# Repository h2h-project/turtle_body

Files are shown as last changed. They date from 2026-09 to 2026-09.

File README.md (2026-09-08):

# turtle_body
The 3D design files that make up the components of the hope turtle's body.  

**Turtle Body** is the open-source mechanical design repository for the [Hope Turtle Project](https://hopeturtles.org): a wind-powered, largely organic marine vessel designed to carry food, building materials, love and hope toward coastal destinations. It is the physical counterpart to [TurtleOS](https://github.com/h2h-project/turtleOS), which handles sensing and autonomous navigation; the TurtleShell PCB, which connects and powers the electronics; and [HopeTurtles.org](https://github.com/h2h-project/hopeTurtles.org), which supports building, mission planning, tracking and discovery reporting. Together, these parts are intended to make Hope Turtles practical to reproduce, study and improve anywhere in the world.

This repository contains the parametric OpenSCAD models and fabrication files used to build the turtle body, including its bottle interfaces, control cap, rotating sail cage, magnetic angle-sensing shaft, bearing surfaces, sail battens and crossbars, chassis connections, rear fin and ballast components. The designs are being developed around ordinary bottles, locally available wooden boards and accessible 3D printing, with core measurements—such as bottle diameter, wood thickness, running clearance, hole size and component spacing—kept adjustable wherever possible. Source `.scad` files are retained as the editable designs from which printable STL models and other fabrication outputs can be generated.

The Turtle Body models are the geometry source behind the turtle generator on [HopeTurtles.org](https://hopeturtles.org/ecojoiners/generate). A builder enters the measurements of locally available bottles, boards and solar panels, and Python generators in the website repository's `generator/` directory produce cutting files for the wooden components. This repository's `lib/params.scad` is the authoritative dimension contract; the generators follow it, and `CLAUDE.md` section 19 records how changes made here are carried across so that each new iteration becomes easier for other builders to reproduce and adapt.

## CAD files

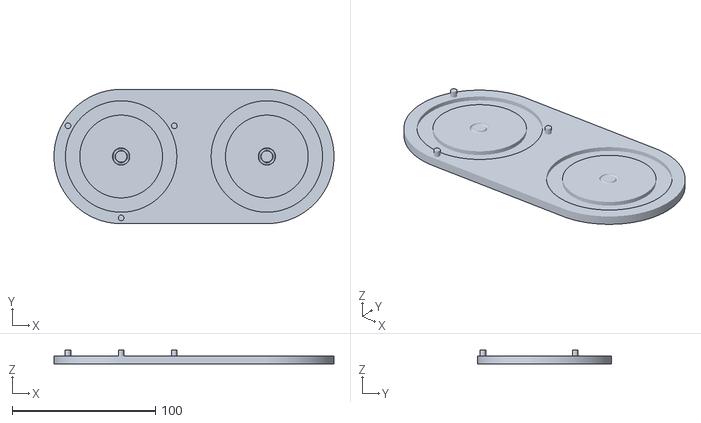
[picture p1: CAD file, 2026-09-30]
stls_v1/Silicone_Ring_Mold_bottom_v4.1.2.stl
195.5 x 93.8 x 9.60

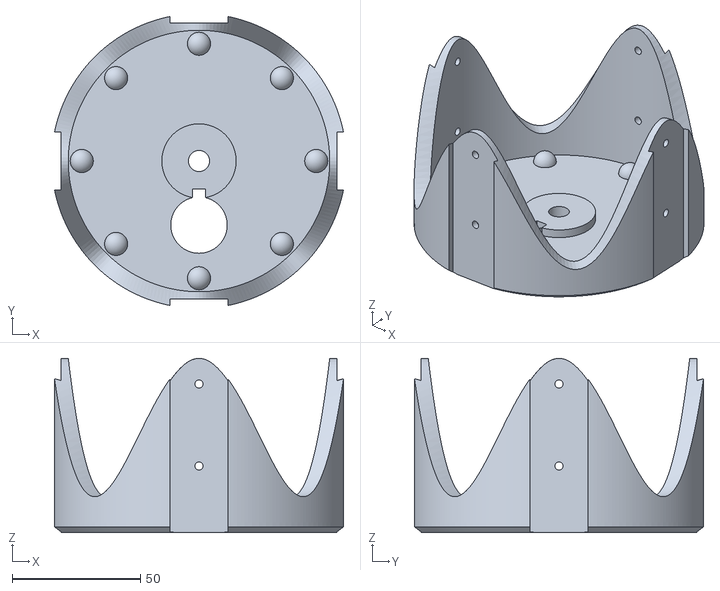
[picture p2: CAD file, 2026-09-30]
stls_v1/Bottle_Control_Cage_v4.1.2.stl
112.8 x 112.8 x 68.0

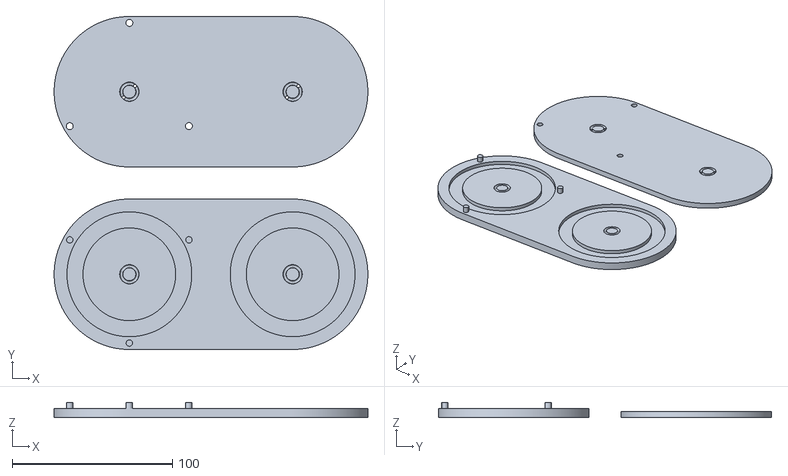
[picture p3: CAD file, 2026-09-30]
stls_v1/Silicone_Ring_Mold_v4.1.2.stl
195.5 x 207.5 x 9.60

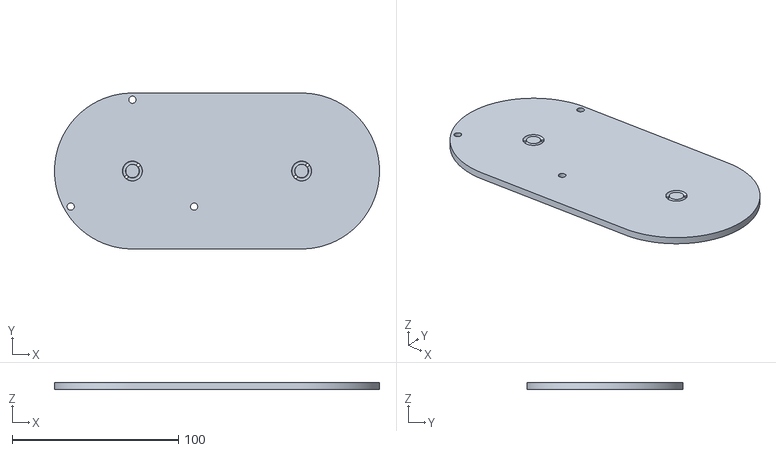
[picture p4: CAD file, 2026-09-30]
stls_v1/Silicone_Ring_Mold_top_v4.1.2.stl
195.5 x 93.8 x 4.00

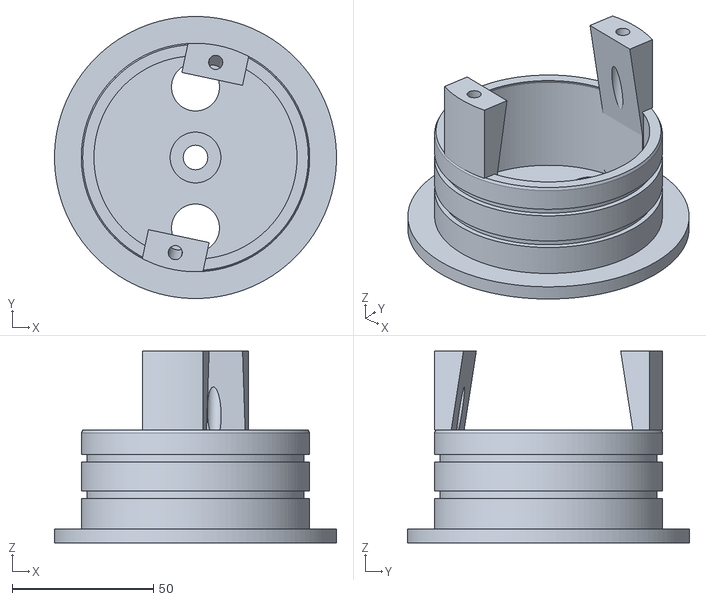
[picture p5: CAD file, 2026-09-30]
stls_v1/Bottle_Control_Cap_v4.1.2.stl
100.0 x 100.0 x 68.0

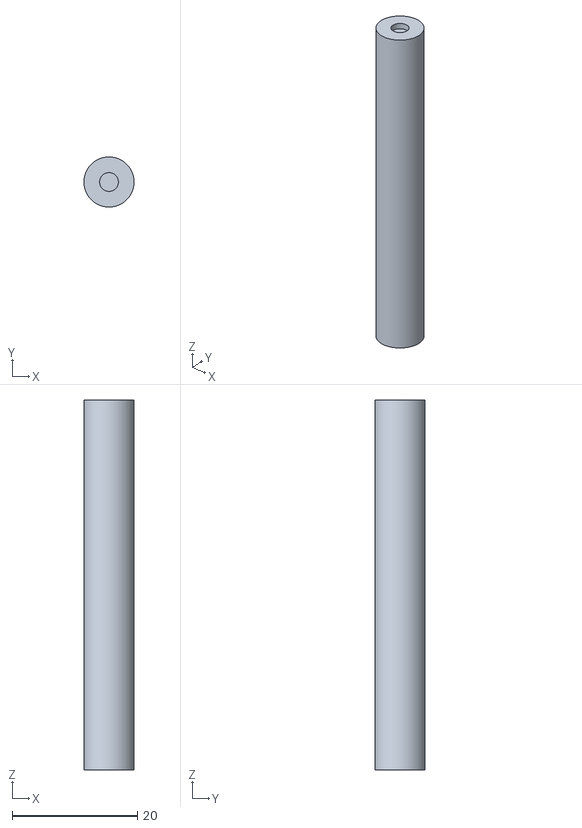
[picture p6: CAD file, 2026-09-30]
stls_v1/Bottle_Sail_Shaft_v4.1.2.stl
8.00 x 8.00 x 59.0

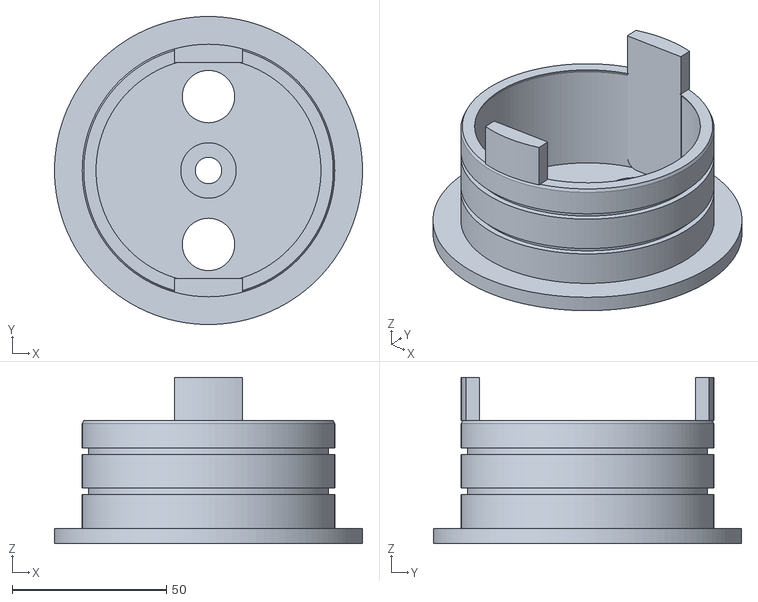
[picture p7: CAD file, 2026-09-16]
stls_v1/Bottle_Control_Cap_v1X.stl
100.0 x 100.0 x 54.0

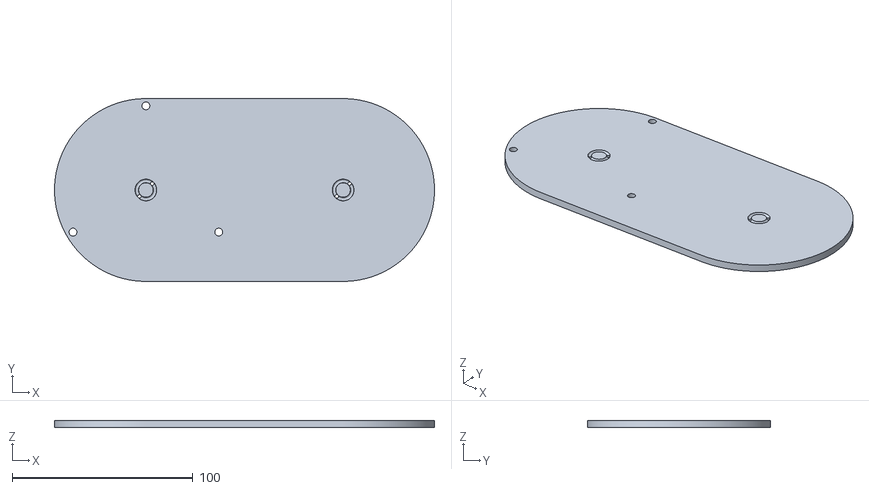
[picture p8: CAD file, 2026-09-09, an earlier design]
stls_v1/Silicone_Ring_Mold_top_v1.10.0.stl
210.0 x 101.0 x 4.00

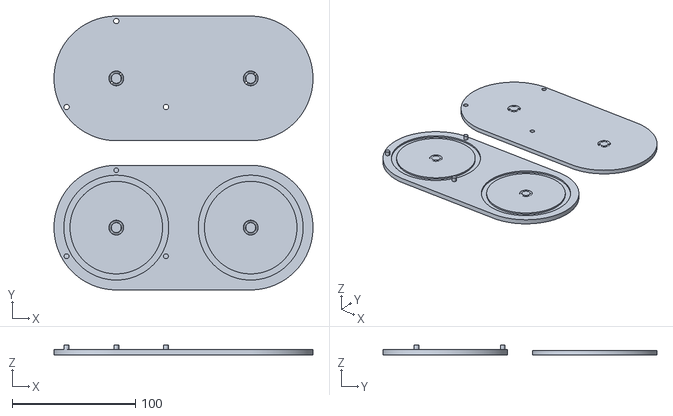
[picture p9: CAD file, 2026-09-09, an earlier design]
stls_v1/Silicone_Ring_Mold_v1.10.0.stl
210.0 x 222.0 x 8.50

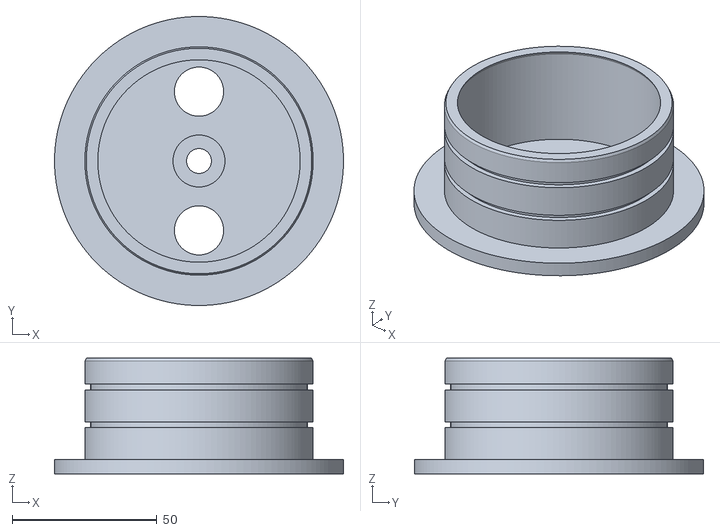
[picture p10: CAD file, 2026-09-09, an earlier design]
stls_v1/Bottle_Control_Cap_v1.10.0.stl
100.0 x 100.0 x 40.0

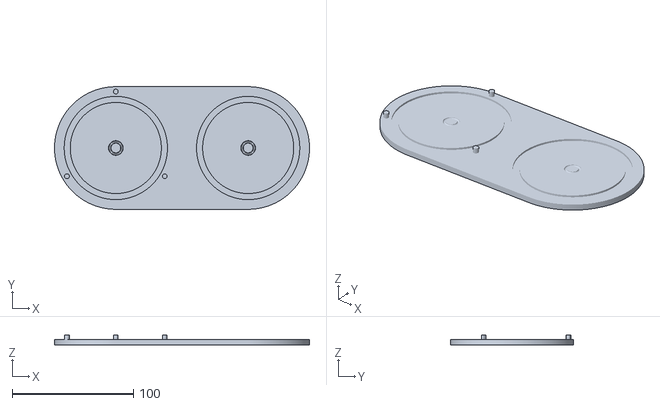
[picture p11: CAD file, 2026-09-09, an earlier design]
stls_v1/Silicone_Ring_Mold_bottom_v1.10.0.stl
210.0 x 101.0 x 8.50

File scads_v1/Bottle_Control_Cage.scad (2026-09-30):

// ==========================================================================
//  GENERATED FILE -- DO NOT EDIT.
//  Produced by build/build.py from components/Bottle_Control_Cage.scad
//  Turtle Body version 4.1.2
//  Edit lib/ and src/ instead, then run: python3 build/build.py
// ==========================================================================
/*
 Hope Turtle — scalloped, reinforced PLA cage. Units: mm.
 Matched to the control cap: 100 mm cap disk, 102 mm cavity, 1 mm radial
 clearance. One continuous sinusoidal wall -> four rounded crests roof-down;
 each batten groove + its two M3 holes centred on a crest. No separate tabs.

 FABRICATION: this part is 3D-PRINTED ROOF-FACE-DOWN — the flat top surface
 goes on the printer bed (part="print" flips it). Any change to the roof top
 must stay self-supporting in that pose: bevels flare OUTWARD from the bed
 (<= 45 deg), no undercut, no downward-facing pocket/lip/overhang. Flag any
 change that would need support material instead of making it silently.
 Horizontal M3 bores bridge in the slicer. The recessed clip pocket around
 the axle is OFF by default (top_pocket) while prototyping without a clip.
 TB-08: the central bore is a plain round hole for the uniform round sail
 shaft (see Bottle_Sail_Shaft.scad); a single radial M3 set screw through
 the hub wall locks the shaft to the cage; it points into the roof button
 opening so a hex key reaches it from above. Prototype: not load-tested.
 Test fit, torsion, bending, layer adhesion, set-screw thread engagement.

 SOURCE FILE — geometry lives in lib/control_cage.scad + lib/params.scad.
 The committed self-contained file is generated by build/build.py.
*/

/* [View] */
part = "print"; // [print,upright]
curve_segments = 120; // [48:12:240]
wave_segments  = 240;  // [120:24:480]

/* [Cage body] */
cage_wall   = 6.5;
cage_roof   = 4;
skirt_height = 44;      // roof underside -> ORIGINAL skirt rim
notch_width = 22.5;
notch_depth = 3.7;
m3_hole_diameter = 3.2;
roof_ring_height = 10;  // minimum skirt depth between mounts
mount_extension  = 20;  // crest past the original rim
lower_hole_from_tip = 10;
roof_bevel = 3;         // 45-deg outward chamfer on the roof-top edge (0 = sharp); prints face-down

/* [Bearings and button] */
bump_d = 9;
button_diameter = 22;  // opens onto the hub face -> set-screw access
button_r = 25;         // matches the cap's button holes (p_button_radius())
button_angle = 90; // [0:0.5:359.5]

/* [Shaft hub, lock screw and clip pocket] */
shaft_hole_diameter = 8.2;  // TB-08: round bore, shaft dia + running clearance (was a hex bore)
cage_hub_d = 29;
setscrew_pilot_diameter = 2.5;  // self-tapping M3 grub-screw pilot, untested thread engagement
setscrew_recess_width = 5;      // key-access recess around the screw (tangential)
setscrew_recess_depth = 3;      //   "  radial, inward from the opening edge (0 = none)
top_pocket = false;      // recessed clip pocket around the axle (off while prototyping)
clip_pocket_depth = 4;   // used only when top_pocket = true
pocket_d = 26;           //   "    "    "     "      "

// [bundle] begin use <../../lib/control_cage.scad>
// ==========================================================================
//  Turtle Body -- rotating control cage  (lib module)
// --------------------------------------------------------------------------
//  An inverted open-bottom cup. One continuous sinusoidal annular wall
//  forms four rounded crests; each batten groove and its two M3 holes are
//  centred on a crest. Eight solid hemispherical bearing bumps ride on the
//  cap's flat face. No bottom plate, no separate tabs. See CLAUDE.md s6.
//
//  Native "installed" reference: bearing tips touch cap Z = 0.
//    roof underside  Z = bump_d/2         (= 4.5 default)
//    roof top        Z = bump_d/2 + roof  (= 10.5)
//    longest tip     Z = -(skirt + extension) + bump_d/2   (= -59.5)
//
//  FABRICATION -- READ BEFORE CHANGING THE ROOF: this part is 3D-PRINTED
//  ROOF-FACE-DOWN. The flat top surface goes on the printer bed (the
//  wrapper's part="print" pose flips it; see CLAUDE.md s6 / s16). Every
//  roof-top feature must be self-supporting in that orientation:
//    * a bevel/chamfer on the roof-top edge must flare OUTWARD as it rises
//      from the bed (<= 45 deg from vertical) -- p_cage_roof_bevel() is a
//      true 45-deg outward chamfer and is printable as-is;
//    * do NOT add a downward-facing pocket, lip or overhang to the roof top,
//      and do NOT make the bevel an undercut (radius growing then shrinking).
//  A change that would need support material in the roof-down pose must be
//  flagged to the user, not silently made. The horizontal M3 bores (batten
//  mounts + the TB-08 shaft set screw) bridge in the slicer; keep them
//  inspectable. The recessed clip pocket around the axle is behind
//  `top_pocket` (OFF by default -- no shaft clip while prototyping).
//
//  TB-08: the central bore is now a plain round hole (shaft_hole_d, shared
//  with the sail bar's own hole) that the uniform round shaft passes
//  through with a light running clearance -- not a shaped (hex)
//  interference fit. A single radial M3 set screw through the hub wall
//  (setscrew_pilot_d/setscrew_angle) presses on the shaft to lock it to the
//  rotating cage. The pilot is a self-tapping hole into the printed PLA hub,
//  not a clearance hole for a separate nut -- untested thread engagement.
//
//  Definitions only. Geometry is emitted by control_cage(); the wrapper /
//  full assembly applies the print-pose or installed transform.
// ==========================================================================

// [bundle] begin use <params.scad>
// ==========================================================================
//  Turtle Body -- shared dimension contract
// --------------------------------------------------------------------------
//  The single source of truth for every dimension that more than one
//  subsystem depends on. Values are exposed as zero-argument functions so
//  this file can be pulled in with `use <params.scad>` (which ignores
//  top-level variable assignments) without polluting any namespace.
//
//  lib/ modules take these as DEFAULT argument values:
//      module control_cap(roof_t = p_cap_roof_t(), ...) { ... }
//  so a src/ wrapper can still override one value from its customizer block
//  while every other subsystem keeps the shared number.
//
//  Rules:
//   * one function per concept, canonical name (see CLAUDE.md cross-file table)
//   * derived values are functions of other p_*() functions, never re-typed
//   * mm throughout; names say _d (diameter), _r (radius), _t (thickness),
//     _len / _h (axial), _af (hex across-flats)
//   * do NOT add a bare `x = ...;` here -- bundle.py / lint.py will reject it
// ==========================================================================

// ---- tolerances and render quality --------------------------------------
function p_eps()          = 0.02;   // Boolean overlap / cut-through fudge
function p_fit_clearance() = 0.2;   // wood joint: TOTAL extra slot width, centred on the board
function p_fn_plastic()   = 120;    // printed PLA parts (cap, cage, axle, mold)
function p_fn_wood()      = 96;     // cut wooden parts
function p_fn_curve()     = 180;    // fine profile curves (bottle, sails)

// ---- bottle (the foundation reference) ---------------------------------
function p_bottle_d()        = 84;    // outside diameter (was 86, and 82 before that; other bottle dims held)
function p_bottle_h()        = 305;   // total height incl. ordinary screw cap
function p_bottle_wall_t()   = 0.5;   // modelling assumption, not a measurement
function p_bottle_cap_d()    = 31;    // ordinary screw cap (NOT the control-cap disk)
function p_bottle_cap_h()    = 17;    // ordinary screw cap height (rear-fin / ballast formulas)
function p_collar_d()        = 34;    // bottle collar, independent of cap diameter
function p_top_dome_h()      = 62;
function p_bottom_dome_h()   = 25;
function p_dome_power()      = 2.5;   // superellipse exponent
function p_bottle_neck_h()   = 5;
function p_bottle_collar_h() = 1;
function p_bottle_neck_d()   = p_bottle_cap_d() - 3;   // 28: neck is 3 mm under the cap
function p_bottle_base_ratio() = 0.88; // slightly narrower footprint at the base
function p_bottle_profile_steps() = 16;
// cut bottle (control head): the lower dome is removed and a short socket is
// bored so the control-cap insert slides in. Cut plane sits 5 mm above the
// bottom dome height.
function p_bottle_cut_extra()  = 5;
function p_bottle_cut_height() = p_bottom_dome_h() + p_bottle_cut_extra();   // 30
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

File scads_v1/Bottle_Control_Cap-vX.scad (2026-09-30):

/*
 Hope Turtle — control cap, EXPERIMENTAL side-tab variant "vX". Units: mm.
 License: CERN-OHL-S-2.0.

 HAND-BUILT ONE-OFF VARIANT — NOT a generated bundle, NOT produced by
 build/build.py, NOT wired into build/manifest.json. Forked from the
 production src/components/Bottle_Control_Cap.scad / lib/control_cap.scad
 (turtle_body v4.0.0). Everything outside the side tabs (disk, insert,
 O-ring gland, band channels, button holes, asserts) is copied verbatim from
 lib/control_cap.scad; only the side-tab placement/taper/wire-channel logic
 below is a hand-modified fork (see the precedent: v1.0
 SCADs/Bottle_Control_Cap_v1XX.scad).

 SELF-CONTAINED (2026-09-23): lib/params.scad and lib/util.scad are pasted
 inline below (between the "[bundle] begin/end" markers), snapshotted at
 turtle_body v4.0.0. No other files are needed to open or render this file.
 Consequence: it no longer tracks lib/params.scad — a later lib change must
 be re-bundled by hand (python3 build/bundle.py on a copy with the two
 `use <../lib/...>` lines restored).

 Revision history (all 2026-09-22):

 Rev 1: no rotation off the button axis; each tab slides sideways by
 tab_side_offset (mirrored +6/-6); taper removed (straight inner face).

 Rev 2/3: chased a "still looks rotated" report by dropping the curved
 (wall-hugging) outer face for a flat one, and fixed the offset from
 mirrored to both-same-direction.

 Rev 4 (this one) — reverts the flat outer face. Confirmed from the actual
 renders: a flat/unclipped outer face is what looked like "ugly rectangles"
 that don't match the cap's round wall. The outer face is curved again —
 intersected against the TRUE cavity-wall / insert-wall cylinders (centred
 on the real cap axis, unmoved), same as lib/control_cap.scad's production
 cap_side_tabs() — so it genuinely follows the wall's own curvature. This is
 safe (not the rev-1 "diagonal" bug) because that block and that cylinder
 are BOTH invariant along Z within each segment: intersecting a fixed 2-D
 footprint with a fixed-radius cylinder, repeated unchanged at every height,
 produces a perfectly vertical curved wall, not a sloped/diagonal one. What
 actually varies is the plan (top-down) shape: since the tab is offset from
 the wall's own centre, its curved outer face naturally sits a little closer
 to the true wall on the side nearer the offset direction and a little
 farther on the other side — that asymmetry IS "matching the curve of a
 wall you're not centred on," not a defect. The two things rev 2/3 also
 fixed are kept:
   - x_off (tab_side_offset) is the SAME for both tabs — a uniform slide,
     not mirrored.
   - Inner face stays a straight vertical line (no taper) top to bottom.
   - Wire channel: 4 mm dia, blind, exits at the radial centre of the cap's
     own insert-wall thickness (not into the hollow cavity), cut in the
     outer/global difference() so it can reach past the tab's own material.
 As in production, the rib (inside the cavity height, Z <= lip_z) clips to
 the true cavity-wall radius (r_outer_true); the lip extension (free-
 standing above the cap's own body, Z > lip_z) clips to the true insert
 outer-wall radius (r_wall_true) — the same real step production always
 had, just now off-axis instead of on it.

 Rev 5 (this one) — two more changes:
  (a) The tab's INNER face is now positioned by a new adjustable variable,
      tab_inner_wall_distance (2 cm / 20 mm default), measured INWARD from
      the true outer wall radius (r_wall_true -- the cap's actual outer
      diameter along the button axis), not from the cavity wall the way
      tab_depth used to work. r_inner = r_wall_true - tab_inner_wall_distance.
      This reaches much deeper into the cap than the old 2 mm tab_depth did
      (r_inner drops from ~34.5 mm to ~20.5 mm at the current 81 mm insert
      diameter) -- comfortably still clear of the centre boss, asserted.
  (b) Wire channel direction reversed back to angling INWARD and breaking
      into the HOLLOW CAVITY, not blind in the solid wall the way rev 2-4
      had it. entry_r stays centred in the tip's own material; exit_r is
      now max(0, r_inner - wire_hole_d) -- a full hole-diameter past the
      (now much deeper) inner face, same formula production always used.
      The open end remains at the tip (outside, where a wire is fed in);
      what changed is where the OTHER end opens -- now on the inside of the
      cap (the cavity), not dead-ending in the wall's own material.

 Rev 6 (this one) — new silicone-seal strategy for the two insert-wrap seal
 grooves (cap_plug_outer()'s one_groove(), separate from the small axle
 O-ring gland). Production/rev 1-5 cut a RECTANGULAR slot (flat floor,
 square corners: 2.7 mm wide x 2 mm deep) meant for a flat cast ring
 (lib/silicone_ring_mold.scad's flat-ring mold). This instead cuts a
 SEMICIRCULAR channel -- open flush with the insert's true outer surface,
 curving inward to a rounded floor -- sized to seat a round-section O-ring:
   band_channel_depth (kept at the same 2 mm) IS the semicircle's radius,
   so the groove's open width is always 2 x band_channel_depth (4 mm), and
   that's also the O-ring's own cross-section diameter -- half its
   thickness recesses into the groove, half stands proud of the surface for
   compression sealing, same convention as the existing axle O-ring gland.
 band_channel_w is gone as an independent input (width is now derived, not
 free); the two groove positions (band1/2_center_z_local) are unchanged.
 NOT yet matched on the casting side: lib/silicone_ring_mold.scad still
 only casts FLAT rectangular rings -- it would need a round-torus mold (like
 the small axle O-ring's own two-part mold there) sized to this new 4 mm
 cross-section before this groove shape could actually be filled with a
 matching cast part. Flagged, not implemented here (out of scope of "the
 groove on the cap" as asked).

 Rev 7 (this one) — two changes:
  (a) tab_inner_wall_distance default 20 -> 12 mm (r_inner now sits ~7.5 mm
      further out, closer to the true outer wall, still clear of the centre
      boss per the existing assert).
  (b) New faint reference etch line: a shallow (0.2 mm deep, 0.6 mm wide)
      groove recessed into the cavity ceiling (roof underside, the inner
      face you see looking up into the hollow insert), spanning the full
      cavity diameter along button_axis -- i.e. it passes through the centre
      bore and both button centres. Alignment mark only, no structural role.
      New inputs: etch_line_enable / etch_line_width / etch_line_depth.

 Rev 8 (this one) — four changes:
  (a) tab_wire_hole_diameter 4 -> 7 mm.
  (b) centre_boss_diameter: 12 mm was requested but fails the existing
      O-ring-gland-clearance assert (needs boss_d > gland OD + 1 mm = 12.5);
      set to 13 mm, the smallest value that still clears it.
  (c) New button_axis_offset (6 mm): both button holes now slide off the
      etched axle line, same direction as tab_side_offset (mirrors the tab
      slide, not mirrored left/right). Clearance asserts on button_radius
      now use the true centre distance (hypot of radius and offset), not
      just the nominal radius.
  (d) Button spacing: 18 mm centre-to-centre was requested but is not
      reachable at the existing 17 mm button diameter (the two holes would
      nearly touch each other and swallow the centre boss/bore). Per
      instruction, kept button_upper_d at 17 mm and used the real minimum
      spacing instead: hole_spacing_cc (radius) 25 -> 15 mm, giving 30 mm
      true centre-to-centre spacing (smallest that clears the 13 mm boss
      with ~1 mm margin, accounting for the offset in (c)).

 Rev 9 (this one) — two changes:
  (a) Tab wire channel's cavity-side opening moved: it now breaks through
      exactly at the cap's own inside corner -- where the flat roof
      (z = roof_t) meets the cavity wall (r = r_outer_true) -- instead of
      partway down the rib at a z = lip_z - wire_hole_exit_from_lip offset
      (that parameter is gone). The open end at the tip is unchanged.
  (b) New rectangular PCB-spacer notch in each tab's leg (the lip-extension
      portion beyond lip_z that sticks out past the cap body): starts
      tab_notch_from_lip (5 mm) past the lip, cuts tab_notch_depth (5 mm)
      radially in from the tab's inner face, and runs tab_notch_height
      (8 mm) further up the leg toward the tip. Full tab width. New module
      cap_tab_notches_vX(); new inputs tab_notch_enable /
      tab_notch_from_lip / tab_notch_depth / tab_notch_height.
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

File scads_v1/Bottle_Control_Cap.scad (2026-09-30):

// ==========================================================================
//  GENERATED FILE -- DO NOT EDIT.
//  Produced by build/build.py from components/Bottle_Control_Cap.scad
//  Turtle Body version 4.1.2
//  Edit lib/ and src/ instead, then run: python3 build/build.py
// ==========================================================================
/*
 Hope Turtle — control cap for the current full-turtle sine cage. Units: mm.
 License: CERN-OHL-S-2.0.
 Cap disk 100 mm; matching cage cavity 102 mm (1 mm radial clearance).
 Print bearing face down at Z=0, open insert + boss facing up.
 5 mm roof + 2 mm internal boss (TB-03).
 The axle bore carries an O-ring gland (rotary seal on the spinning axle
 round section) -- waterproofs the bore. O-ring is cast in Silicone_Ring_Mold.
 Side tabs (two internal cavity ribs + lip extension, on by default) are a
 fit/registration experiment -- not validated. See lib/control_cap.scad.
 Each tab carries a 5 mm wire-routing channel down to the cavity, for
 button wiring.

 SOURCE FILE — geometry lives in lib/control_cap.scad + lib/params.scad.
 The committed self-contained file is generated by build/build.py.
*/

/* [Cap body] */
top_disk_thickness  = 5;   // roof / disk thickness
centre_boss_depth   = 1.5; // extra projection of the boss into the hollow cap (was 2; lowered 0.5 mm)
centre_boss_diameter = 18;
cup_wall_thickness  = 4;
insert_total_h      = 35;
entry_chamfer_h     = 1;
entry_chamfer_delta = 1;

/* [Axle and buttons] */
shaft_hole_d   = 8.7;  // 0.35 mm radial clearance to the Ø8 axle (was 8.6 / 0.3 mm)
button_upper_d = 17;
button_axis    = "y"; // [x,y]
hole_spacing_cc = 25;  // radial position of the two button centres (was 24; moved 1 mm out,
                        // shared with the cage's matching bore via p_button_radius())

/* [Axle O-ring gland] */
oring_gland_enable = true;
oring_gland_od = 11.5;      // groove bottom diameter in the bore
oring_gland_width = 2.6;    // groove axial width
oring_gland_from_face = 3.5; // groove centre, below the cap outer face

/* [Silicone band channels] */
band_channels_enable = true;
band_count = 2;             // [0:1:2]
band1_center_z_local = 12;  // groove centre, from the insert shoulder
band2_center_z_local = 25;
band_channel_w = 2.7;      // groove axial height (matches the retuned mold ring)
band_channel_depth = 2;    // groove radial depth

/* [Side tabs] */
// Two internal ribs on the hollow insert cavity's inner wall, on the button
// axis, running the full cavity height then continuing past the top lip as
// a free post with a gradual inward taper. Not validated -- a
// fit/registration experiment; see lib/control_cap.scad.
side_tabs_enable = true;
tab_width  = 22;   // tangential width, measured at the cavity-wall radius
tab_depth  = 2;    // radial projection inward from the cavity wall
tab_top_overhang = 28;  // how far the tabs continue past the top lip
tab_corner_fillet = 4;  // rounds the two bottom edges where the tab meets the floor
tab_tip_taper_gain = 6; // total inward (radial) lean of the inner face by the free tip
tab_taper_start = 10;   // taper begins this far below the lip
tab_rotate = -12;        // extra rotation of the tab pair about Z, off the button
                         // axis (- = clockwise, viewed from above)

/* [Tab wire hole] */
// A 5 mm channel drilled down each tab from its exposed free tip, angled
// so it breaks through into the hollow cavity for routing button wires.
tab_wire_hole_enable = true;
tab_wire_hole_diameter = 5;
tab_wire_hole_exit_from_lip = 15;  // how far below the lip the channel opens into the cavity

/* [Render] */
fn = 120; // [48:8:240]

// [bundle] begin use <../../lib/control_cap.scad>
// ==========================================================================
//  Turtle Body -- control cap  (lib module)
// --------------------------------------------------------------------------
//  The large stationary disk. Its insert enters the cut bottle body; the
//  rotating cage sits above its flat outer face. NOT the bottle's Ø31 screw
//  cap. See CLAUDE.md s7 / s8.
//
//  TB-03: 5 mm roof + 2 mm internal boss (7 mm axle bearing length).
//  The boss is joined to the roof with a Boolean overlap and survives the
//  cavity subtraction; the central bore passes through both.
//
//  The bore carries an O-RING GLAND (`oring_gland`, on by default): an
//  annular groove in the bore wall that seats a round-section rotary-seal
//  O-ring against the spinning axle round section, waterproofing the bore.
//  The O-ring is cast in lib/silicone_ring_mold.scad; its ID is tied to the
//  axle shaft (p_axle_oring_id() = p_axle_round_d()).
//
//  Optional SIDE TABS (`side_tabs`, off by default in this module but ON in
//  the wrapper): two internal ribs on the hollow insert cavity's inner wall,
//  rooted at the cavity floor, that continue past the top lip as a free
//  full-wall-thickness post with a gradual inward taper. See cap_side_tabs()
//  below. Not validated -- a fit/registration experiment.
//
//  Optional TAB WIRE HOLE (`tab_wire_hole`, off by default, ON in the
//  wrapper alongside side_tabs): a round channel drilled down each side
//  tab from its exposed free tip to a point inside the cap body, breaking
//  through the tab's inner face into the hollow cavity -- for routing
//  button wires from outside, down through the tab, into the cap interior.
//
//  Definitions only. Geometry is emitted by control_cap().
// ==========================================================================
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

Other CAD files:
stls_v1/Bottle_Control_Cage_v1.10.0.stl
v1.0 SCADs/Bottle_Control_Cap_v1X.scad
Full_Turtle_v1.scad
_hole_probe5.scad
scads_v1/Bottle_Sail_Shaft.scad
scads_v1/Silicone_Ring_Mold-vX.scad
scads_v1/Silicone_Ring_Mold.scad
scads_v1/Turtle_Bottom_Ballast_Fin.scad
scads_v1/Turtle_Core_Ecojoiner.scad
scads_v1/Turtle_Rear_Fin.scad
scads_v1/Turtle_Sail_Apparatus.scad
src/Full_Turtle.scad
src/components/Bottle_Control_Cage.scad
src/components/Bottle_Control_Cap.scad
src/components/Bottle_Sail_Shaft.scad
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

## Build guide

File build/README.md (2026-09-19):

# Turtle Body build system

Local, no network, no CI service. Python 3 standard library + OpenSCAD only.

## Layout

| Path | Role |
| --- | --- |
| `lib/*.scad` | **Editable.** One parametric module per subsystem, plus `params.scad` (the shared dimension contract, exposed as `function p_*()`), plus `util.scad`. Definitions only — no top-level geometry, no top-level variable assignments. |
| `src/Full_Turtle.scad`, `src/components/*.scad` | **Editable.** Thin wrappers: customizer block + `use <../lib/...>` + a `part=` / `assembly_view` dispatch. No geometry of their own. |
| `Full_Turtle_v1.scad`, `scads_v1/*.scad` | **Generated. Do not edit.** Self-contained bundles produced from `src/` + `lib/`. Committed so they stay downloadable and STL-ready. A banner marks them. |
| `stls_v1/*_v<version>.stl` | Fabrication exports, written on demand by `export_stl.py`. Not auto-committed. |
| `build/params.json` | **Generated. Do not edit.** Every `lib/params.scad` `p_*()` value + the version, from `export_params.py` (run by `build.py`, checked by `lint.py`). The machine-readable contract the HopeTurtles.org generators sync against — see CLAUDE.md §19. |
| `build/manifest.json` | Every renderable target: its `src`, its generated `out`, and the `-D` defines for each render. |
| `tests/expected_bounds.json` | Regression baseline (bounding box + triangle count per render) that `test.py` checks. |
| `tests/baseline/*.json` | Full per-render dump from the last `baseline.py` run (bounds, echoes, warnings, timing). |
| `VERSION.json` | Single set-level version + changelog. |

## Scripts

```bash
python3 build/build.py            # regenerate every bundle + build/params.json  (the sync step)
python3 build/build.py --check    # fail if a committed bundle or params.json is stale
python3 build/export_params.py    # just the p_*() -> build/params.json snapshot (build.py runs this)
python3 build/lint.py             # bundle + params freshness + git whitespace + OpenSCAD CSG parse + lib hygiene
python3 build/test.py             # mesh every render, compare bounds/warnings to the baseline (maintainer-run — see workflow)
python3 build/baseline.py         # re-record the baseline (only when geometry changes are intentional; maintainer-run)
python3 build/export_stl.py       # write the PLA-part STLs, version-stamped
python3 build/bundle.py SRC.scad  # inline use/include for one file (build.py uses this)
```

`OPENSCAD=/path/to/openscad` overrides binary discovery (PATH → `~/.local/bin` → macOS app bundle).

## Change workflow

1. Edit **only** `lib/` and/or `src/`. Never edit a generated bundle.
2. `python3 build/build.py` — propagates to `Full_Turtle_v1.scad` and every `scads_v1/*.scad`.
3. `python3 build/lint.py`
4. Visually inspect the change in OpenSCAD. `build/test.py` is **not** run automatically
   (it is slow, and it only detects change vs. baseline in renders you did not open) — run it,
   and `baseline.py` if a bounds change is intentional, only for a shared-contract edit
   (`lib/params.scad`, `lib/util.scad`, a shared module signature) or before a commit / STL
   release. Review the `tests/expected_bounds.json` diff as the sign-off. See CLAUDE.md §15
   step 5 for the full policy (agents recommend the run and wait; they do not run it themselves).
5. Bump `VERSION.json`: `+0.0.1` component-scoped, `+0.1.0` full-turtle-scoped, `+1.0.0` bottle/
   hardware interface break. Append a `changelog` entry.
6. `python3 build/export_stl.py` when new fabrication files are actually needed.

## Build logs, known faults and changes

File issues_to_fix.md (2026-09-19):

# Turtle Body — open issues

Last updated **2026-09-07**. Read `CLAUDE.md` for design rationale, the build
workflow (§15) and current dimensions. Resolved items have been removed; their
history is in `VERSION.json` and the `CLAUDE.md` changelog.

## Resolved (for the record)

The shared-library refactor (M0–M8) is complete. **TB-01, TB-02, TB-03, TB-04,
TB-07 are applied to both the standalone components and the full assembly** — all
geometry now flows from `lib/` and `build/build.py`. TB-05's core (a real
OpenSCAD 2021.01 regression baseline + `build/test.py` enforcement) is in place.
The one recorded intentional bounds change is the TB-03 cap roof 8 → 5 mm, which
drops `full_turtle` / `top_sail` Z-max to 306.5 (noted in
`tests/expected_bounds.json`). No source drift remains; open items below are
physical / interface checks, an external hookup, and an STL release.

---

## CH-2 — Verify rotating-assembly retention (physical + inspection)  — P2

`hope_turtle_sail_apparatus` still has no modelled axial lock. A hex fit
transmits torque but does not stop the cage/axle separating.

- Inspect the centre clip pocket and identify (or add) the retaining feature.
- Confirm hex angular phase and full engagement between axle, cage bore and
  sail-bar hole after the CH-1 transforms.
- Record the magnet-face and AS5600 sensor-plane positions once CH-1 fixes the
  cap/axle datum.

---

## TB-06 (residual) — Build the generator sync mechanism (S-5)  — P3, external

Every recorded drift item is fixed as of 2026-09-08 (list below, for the record). What
remains is S-5 only: the automatic sync mechanism, deliberately deferred in favor of
hand-fixing directly. Without it, the next turtle_body release needs this same manual
comparison redone by hand — see the closing paragraph below.

The generators live in `../hopeTurtles.org/generator/` (`objects/ecojoiner_6fc.py`,
`objects/back_fin.py`, `objects/ballast.py`, `objects/sails.py` + their reference
scripts). The bridge contract is `CLAUDE.md` §19 here and "Turtle Generator" in
that repository's `CLAUDE.md`; the ordered work plan is
`../hopeTurtles.org/generator/SYNC_PLAN.md` (S-1…S-6) and the running log is
`generator/SYNC_LOG.md`. Recorded drift as of 2026-09-08 (lib wins):

- ~~Rear fin~~ **fixed 2026-09-08**: shaft hole Ø6.0 → 6.4; hole 50 mm from front →
  TB-07 formula (103), now derived rather than a constant.
- ~~Ballast~~ **fixed 2026-09-08**: defaults 15/320/35 → 12/305/31; slat 4.5·t → 6·t;
  also found and fixed a missing M6 mount hole (none existed) and a latent bug where
  the shoulder cut read `port_length` instead of `bottle_diameter`.
- ~~Sails~~ **fixed 2026-09-08**: bottle diameter and cap/collar/dome heights are now
  real inputs (the SCAD already accepted them; only the Python wrapper never passed
  them through). SVG/DXF/PDF writers were also missing entirely for all 7 part
  shapes — added and verified against real OpenSCAD-rendered bounding boxes.
- ~~6FC Ecojoiner~~ **fixed 2026-09-08**: Master John + 5 Little Johns → 6 Little
  Johns; cap/collar/port height 32/32/85 → 31/34/82; screw 4.5 → Ø6.4. `objects/six_fc.py`
  renamed `objects/ecojoiner_6fc.py` (internal only — object_type and job-slug unchanged).
- ~~Port length~~ **fixed in v1.7.2**: lib had flattened it to a constant 82; it is
  now `p_top_dome_h() + p_port_allowance()`, the same rule the generators use.

This repository's share (S-5, the automatic sync mechanism): still open, deliberately
deferred in favor of hand-fixing the drift directly (2026-09-08). Would add
`build/export_params.py` writing `build/params.json` from every `p_*()`, hooked into
`build/build.py`, so the next turtle_body release doesn't need this comparison redone
by hand.

---

## TB-08 — Choose and validate the silicone-ring prototype  — P2, physical

Committed mold: Ø75 ID, Ø85 OD, 1.5 mm axial, 5 mm radial width. Ø85 inside an
assumed Ø81 bottle needs 2 mm radial deflection — may wrinkle/roll/distort. A
milder alternative (3.5 mm radial width → Ø82 OD, 0.5 mm interference) was
suggested but not implemented (`p_seal_ring_radial_w()` still 5).

Before treating the mold as final: measure the real bottle interior at both
groove positions on two perpendicular axes; identify the actual silicone product
and cured hardness; test demolding, insertion, retention and leakage; then set
`p_seal_ring_radial_w()`. The ring is not the whole seal — the axle and button
openings are separate interfaces.

---

## TB-05 (residual) — Release STLs from current sources  — P1 before a fabrication release

`stls_v1/` still holds the original four exports. Before publishing a matched
set, regenerate with `python3 build/export_stl.py` (writes
`<name>_v<version>.stl`) and keep the `VERSION.json` version + `source_commit`
current so each STL's provenance is recorded.

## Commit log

2026-09-06 Upload of full set of version 1.0 SCADs and STLs. Here we go!
    [Bottle_Control_Cage_v1.scad, Bottle_Control_Cap_v1.scad, Bottle_Control_Cap_v1.stl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]
2026-09-07 v1.6 revamp of full turtle design and all components
    [Bottle_Control_Cage_v1.scad, Bottle_Control_Cage_v1_v1.6.0.stl, Bottle_Control_Cap_v1.scad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]
2026-09-09 v1.10 stls
    [Bottle_Control_Cage_v1.scad, Bottle_Control_Cage_v1_v1.10.0.stl, Bottle_Control_Cap_v1.scad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]
2026-09-30 v4,12 stls for Sept sea testing
    [Bottle_Control_Cage.scad, Bottle_Control_Cage_v4.1.2.stl, Bottle_Control_Cap-vX.scad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]
2026-10-22 v6.3.4: head fin, split sail crossbar, shorter battens + STLs
    Head fin (new, experimental): front attachment on the -X port, the rear
    fin's mirror. Two 382 mm slats bolt to the front Little John M5 pairs and
    half-lap into a 93 x 192 mm raked fin (36 mm flat nose, 45 deg bottom
    cut). New lib/head_fin.scad, wrapper and scads_v1/Turtle_Head_Fin.scad.
    Sail frame: the 504 mm top crossbar is split into two 212.2 mm halves on
    top of a 159.6 mm centre connector, which has a 9 mm shaft hole and a
    side M3 (2.8 mm pilot) that clamps the shaft. Sail battens 217 mm with a
    24 mm two-layer notch; non-sail battens 178 mm, flush with the cage roof.
    Bottom rails 264 mm. Cage hub set screw switched off (kept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
